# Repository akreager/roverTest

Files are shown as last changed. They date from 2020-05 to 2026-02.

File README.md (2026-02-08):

# Rover Test Platform
Engineering test platform for developing RC rover control and telemetry. Pairs with the [RC Transmitter](https://github.com/akreager/rc-transmitter).

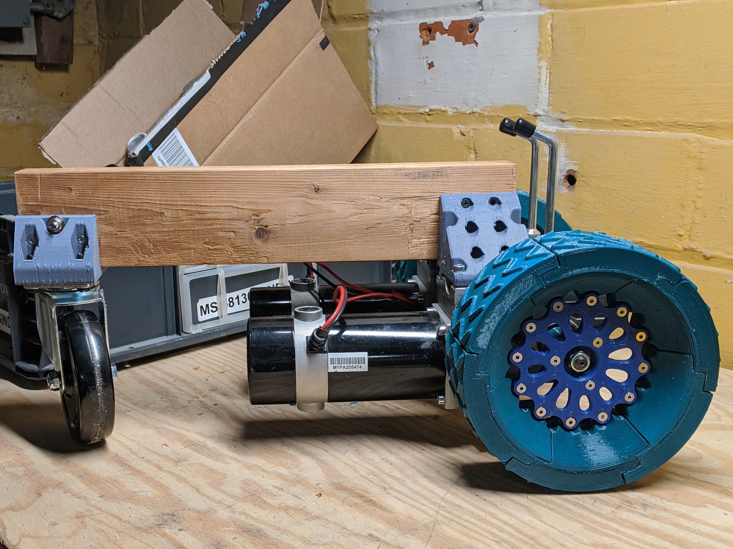
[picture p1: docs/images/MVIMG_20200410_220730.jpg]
Front


## Overview
A small-scale test rover used to develop and validate control, telemetry, and safety features before deploying them on full-size vehicles (e.g. RC snowblower). Receives wireless commands from a custom pistol-grip transmitter and sends back real-time sensor data via nRF24L01+ acknowledge payloads.

### Features
- **Wireless control** via nRF24L01+ with bidirectional telemetry
- **Mixed-mode drive** — throttle and steering via RoboClaw motor controller
- **Telemetry reporting** — battery voltage, board temperatures, motor currents sent back to transmitter each cycle
- **Connection failsafe** — motors stop automatically if radio link is lost for >1 second
- **Motor stop** (M-Stop) — responds to transmitter's M-Stop flag, controls motor enable/disable via digital pin

### Planned
- Joystick-aimed chute control (additional servo/actuator channels)
- Per-vehicle configuration via SD card profiles on transmitter side

## Hardware
- Arduino Mega
- nRF24L01+ radio module (SPI, CE=D49, CSN=D53)
- [Basicmicro RoboClaw](https://www.basicmicro.com/) motor controller (Serial1, address 0x80, 38400 baud)
- Motor enable/disable on D7

## Project Structure
```
RoverTest/
├── main/                 # Receiver firmware (Arduino IDE)
│   └── main.ino          # Radio receive, RoboClaw control, telemetry, failsafe
├── test_sketches/        # Standalone test/reference sketches
│   ├── simpleJoystick/   # Raw joystick → serial output
│   ├── roverJoystick/    # Direct joystick → RoboClaw
│   ├── roverJoyRead/     # Joystick + RoboClaw telemetry → LCD
│   ├── roverRX/          # nRF24 receiver + RoboClaw (precursor to main)
│   ├── roverReceiver/    # Joystick → RoboClaw variant
│   ├── roverRead/        # RoboClaw telemetry → serial LCD
│   ├── roverReadVersion/ # RoboClaw firmware version check
│   ├── PacketSerialMixedPWM/ # RoboClaw mixed mode basic test
│   ├── LCD_Test/         # Serial LCD test
│   └── while/            # LCD + LED loop test
├── stl/                  # 3D printed chassis files
├── docs/                 # Documentation and images
├── LICENSE               # GPLv3
└── README.md
```

## Radio Protocol
The rover receives a `dataPackage` and responds with an `ackPackage` via nRF24L01+ acknowledge payloads. These structs must match the transmitter exactly.

```c
// Transmitter → Rover
struct dataPackage {
  byte throttle;        // 0-127, 64 = stop (RoboClaw mixed mode)
  byte steering;        // 0-127, 64 = center
  bool data_motor_stop; // true = motors disabled
};

// Rover → Transmitter (acknowledge payload)
struct ackPackage {
  byte highBatt, lowBatt;     // Battery voltage, tenths of a volt
  byte highTemp1, lowTemp1;   // Board temp 1, tenths of a degree C
  byte highTemp2, lowTemp2;   // Board temp 2, tenths of a degree C
  byte highIM1, lowIM1;       // Motor 1 current, hundredths of an amp
  byte highIM2, lowIM2;       // Motor 2 current, hundredths of an amp
  bool ack_motor_stop;        // Current motor stop state
};
```

## Dependencies
Install via Arduino IDE Library Manager:
- [RF24](https://github.com/tmrh20/RF24/) (TMRh20 fork)
- [RoboClaw Arduino Library](https://github.com/basicmicro/roboclaw_arduino_library)

## Development
This project is developed with assistance from Claude (Anthropic), used for code architecture, refactoring, and documentation.

## License
This project is licensed under the GNU General Public License v3.0 — see [LICENSE](LICENSE) for details.

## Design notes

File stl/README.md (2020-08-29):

## CAD source
Rover 3D design is being built on [OnShape](https://cad.onshape.com/documents/239133669f4d5c1c58381066/v/e138f06f4808e5e6169b5c82/e/71e3041a4af3a245cfc2c266)

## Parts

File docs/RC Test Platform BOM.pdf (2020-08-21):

RC Test Platform BOM | BOM - RC Test Platform (Main) - Final Assembly

8/21/2020 10:02:41

Document: [1] | RC Test Platform | Open in Onshape
Workspace: [2] | Main [3]
BOM of Assembly: [4] | Final Assembly | BOM Type: | Workspace
Description | | Created: | 2020-08-21 [5]
Part number:
Revision:
State: | RELEASED
ITEM | QTY | NAME | DESCRIPTION [6] | PART NUMBER [7]REVISION | STATE
1 | 1 | Cover | Arduino Mega/Roboclaw Control Box Cover | IN_PROGRESS
2 | 1 | Base | Arduino Mega/Roboclaw Control Box Base Plate | IN_PROGRESS
3 | 4 | Chamfered plain washer normal M8 | Chamfered plain washer normal M8 Steel Zinc Plated | | IN_PROGRESS
4 | 4 | Chamfered plain washer normal M3 | Chamfered plain washer normal M3 Steel Zinc Plated | | IN_PROGRESS
5 | 1 | Caster Bracket | IN_PROGRESS
6 | 4 | Standoff | M3 x 5mm Standoff | IN_PROGRESS
7 | 4 | Socket button head screw M8x1.25 x 30 | Socket button head screw M8x1.25 x 30 Steel Black Oxide | | IN_PROGRESS
8 | 6 | Type A flat washer 1/4 | Type A flat washer 1/4 Steel Zinc Plated | | IN_PROGRESS
9 | 4 | Hex socket head cap screw M6x1.00 x 35 | Hex socket head cap screw M6x1.00 x 35 Stainless Steel | | IN_PROGRESS
10 | 4 | Hex socket head cap screw M6x1.00 x 20 | Hex socket head cap screw M6x1.00 x 20 Stainless Steel | | IN_PROGRESS
11 | 6 | Hex socket head cap screw M3x0.50 x 14 | Hex socket head cap screw M3x0.50 x 14 Steel Black Oxide | | IN_PROGRESS
12 | 4 | Wire Retainer | Dewalt Battery Holder | IN_PROGRESS
13 | 4 | Hex socket head cap screw M3x0.50 x 8 | Hex socket head cap screw M3x0.50 x 8 Steel Black Oxide | | IN_PROGRESS
14 | 1 | Riser Bracket | IN_PROGRESS
15 | 2 | Dewalt DCB | IN_PROGRESS
16 | 4 | 14-16 AWG Male Disconnect | | | IN_PROGRESS
17 | 1 | MC30A_V5 | Roboclaw Motor controller | IN_PROGRESS
18 | 34 8-32 Long Heat-Set Threaded Insert | 93365A142 | IN_PROGRESS
19 | 60 Socket countersunk head cap screw #8-32 x 0.625 Socket countersunk head cap screw #8-32 x 0.625 Stainless Steel | IN_PROGRESS
20 | 4 | Hex thin nut grade A & B M8 | Hex thin nut grade A & B M8 Steel Zinc Plated | | IN_PROGRESS
21 | 2 | Top Gearbox Bracket | IN_PROGRESS
22 | 6 | Hex nut 1/4-20 | Hex nut 1/4-20 Steel Zinc Plated | IN_PROGRESS
23 | 1 | Hex nut 3/8-16 | Hex nut 3/8-16 Steel Zinc Plated | IN_PROGRESS
24 | 2 | M3 Flanged Press-Fit Threaded Insert | | 94510A240 | IN_PROGRESS
25 | 15 M3 Heat-Set Threaded Insert | IN_PROGRESS
26 | 1 | 2x4x18-SS | 18" Long 2x4 | IN_PROGRESS
27 | 4 | Output Shaft | IN_PROGRESS
28 | 4 | Spokes | IN_PROGRESS
29 | 2 | Hub | IN_PROGRESS
30 | 7 | Tube, LH Tread | IN_PROGRESS
31 | 7 | Tube, RH Tread | IN_PROGRESS
32 | 1 | Arduino Mega 2560 | IN_PROGRESS
33 | 2 | Right Cover Plare | IN_PROGRESS
34 | 4 | Gearbox | IN_PROGRESS
35 | 4 | Motor Shaft Cover | IN_PROGRESS
36 | 2 | Left Motor | IN_PROGRESS
37 | 2 | Right Motor | IN_PROGRESS
38 | 2 | Left Cover Plate | IN_PROGRESS
39 | 1 | Antenna base | IN_PROGRESS
40 | 1 | NRF24L01L | IN_PROGRESS
41 | 1 | Antenna top | IN_PROGRESS
42 | 1 | Threaded Rod | IN_PROGRESS
43 | 1 | Threaded Rod | IN_PROGRESS
44 | 1 | Swivel | IN_PROGRESS
45 | 1 | Base | IN_PROGRESS
46 | 1 | Wheel | IN_PROGRESS
47 | 2 | Strain Relief | IN_PROGRESS
48 | 2 | Body | IN_PROGRESS
49 | 1 | LH Lower Gearbox Bracket | | | IN_PROGRESS
50 | 1 | RH Lower Gearbox Bracket | | | IN_PROGRESS
51 | 1 | Hex cap screw 3/8-16 x 2.375 x 1 | Hex cap screw 3/8-16 x 2.375 x 1 Steel | | IN_PROGRESS
52 | 1 | 40x40x10 PC Fan | IN_PROGRESS

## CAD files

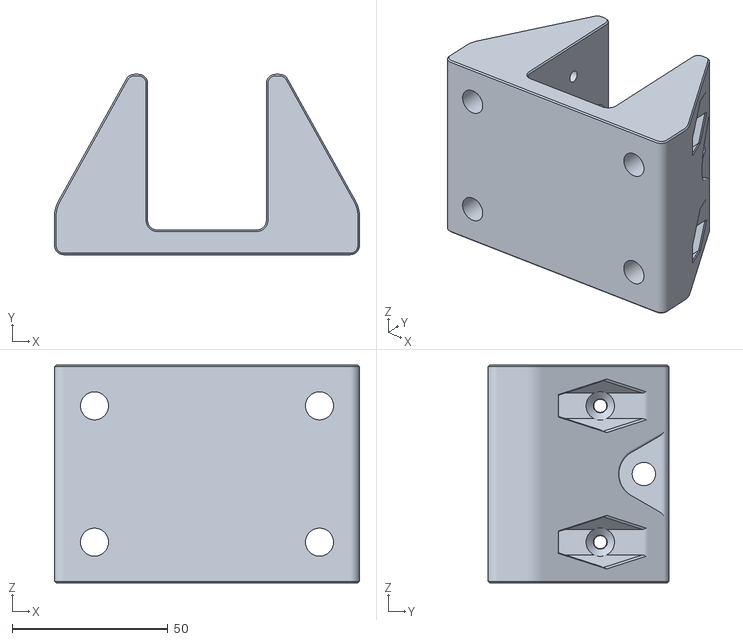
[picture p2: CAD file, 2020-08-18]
stl/Caster Bracket.stl
98.0 x 58.0 x 70.0

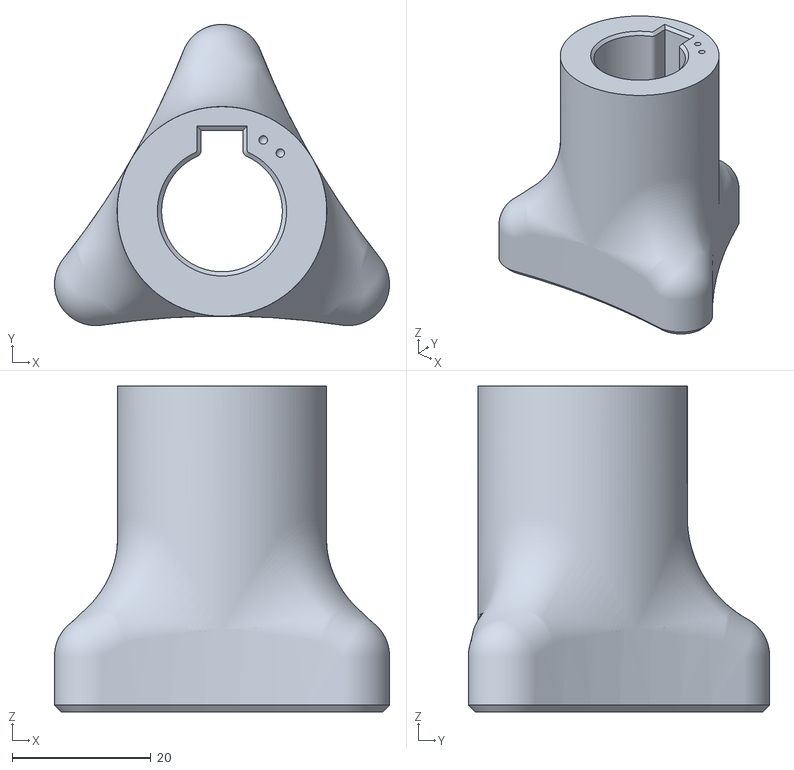
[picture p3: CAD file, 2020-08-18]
stl/Modular Wheel Hub.stl
48.3 x 43.4 x 47.0

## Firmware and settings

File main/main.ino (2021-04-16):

/*
  Optimized fork of nRF24L01 for Arduino & Raspberry Pi/Linux Devices:
  TMRh20/RF24, https://github.com/tmrh20/RF24/
  nRF24/RF24 is licensed under the
  GNU General Public License v2.0

  nRF24 examples used:
  https://howtomechatronics.com/tutorials/arduino/arduino-wireless-communication-nrf24l01-tutorial/
  https://howtomechatronics.com/projects/diy-arduino-rc-transmitter/

  Basicmicro Roboclaw Arduino library and examples:
  https://github.com/basicmicro/roboclaw_arduino_library
*/
//Include libraries
#include <Arduino.h>
#include <SPI.h>
#include <nRF24L01.h>
#include <RF24.h>
#include <RoboClaw.h>

//Declare C++ functions to be used
void failsafe_connection_dropped();
void read_rf_data();
void read_roboclaw_data();
void update_acknowledge_package();
void disable_motors();
void enable_motors();

//nRF24 connected to hardware SPI at address 00001
#define CE_PIN 49
#define CSN_PIN 53
RF24 radio(CE_PIN, CSN_PIN);
const byte nRFaddress[6] = "00001";

//Roboclaw connected to Serial1 at address 0x80
RoboClaw roboclaw(&Serial1, 10000);
#define roboclaw_address 0x80
#define motor_stop_pin 7

//Declare variables
uint16_t rawBattery = 0;
uint16_t rawTemp1 = 0;
uint16_t rawTemp2 = 0;
int16_t rawCurrentMotor1 = 0;
int16_t rawCurrentMotor2 = 0;
unsigned long lastReceiveTime = 0;
unsigned long currentTime = 0;
int readInterval = 0;
int readThreshold = 10;

//Declare flags
bool flag_motor_stop = true;

//package to contain incoming data
struct dataPackage {
  byte throttle;
  byte steering;
  bool data_motor_stop;
};
dataPackage data;

//package to contain outgoing acknowledge data
struct ackPackage {
  byte highBatt;
  byte lowBatt;
  byte highTemp1;
  byte lowTemp1;
  byte highTemp2;
  byte lowTemp2;
  byte highIM1;
  byte lowIM1;
  byte highIM2;
  byte lowIM2;
  bool ack_motor_stop;
};
ackPackage ack;

void setup() {
  pinMode(motor_stop_pin, OUTPUT);

  //start wireless connection
  update_acknowledge_package();
  radio.begin();
  radio.openReadingPipe(0, nRFaddress);
  radio.setDataRate(RF24_250KBPS);
  radio.setPALevel(RF24_PA_MIN);
  radio.enableAckPayload();
  radio.writeAckPayload(0, &ack, sizeof(ackPackage));
  radio.startListening();
  
  //Communciate with roboclaw at 38400 baud
  failsafe_connection_dropped();
  roboclaw.begin(38400);
  roboclaw.ForwardBackwardMixed(roboclaw_address, data.throttle);
  roboclaw.LeftRightMixed(roboclaw_address, data.steering);
}

void loop() {
  // Check whether there is data to be received
  if (radio.available()) {
    read_rf_data();
  }

  //verify connection is alive
  currentTime = millis();
  if (currentTime - lastReceiveTime > 1000 ) {
    //failsafe condition if connection lost
    failsafe_connection_dropped();
  }

  //retreive data from roboclaw for acknowledge payload
  if (readInterval >= readThreshold) {
    read_roboclaw_data();
    readInterval = 0;
  }
  readInterval++;
}

void failsafe_connection_dropped() {
  //Failsafe condition if there is no radio connection
  disable_motors();
  data.throttle = 64;
  data.steering = 64;
}

void read_rf_data() {
  //Read data from nRF module
  radio.read(&data, sizeof(dataPackage));
    lastReceiveTime = millis();
    radio.writeAckPayload(0, &ack, sizeof(ackPackage));

    //Forward received data roboclaw
    roboclaw.ForwardBackwardMixed(roboclaw_address, data.throttle);
    roboclaw.LeftRightMixed(roboclaw_address, data.steering);

    //Check M-Stop flag
    if (flag_motor_stop == true && data.data_motor_stop == false) {
      enable_motors();
    }
    else if (flag_motor_stop == false && data.data_motor_stop == true) {
      disable_motors();
    }
}

void read_roboclaw_data() {
  //Read data fromm roboclaw
  //main battery voltage, tenths of a volt
  bool valid1;
  rawBattery = roboclaw.ReadMainBatteryVoltage(roboclaw_address, &valid1);
  //rawBattery = roboclaw.ReadMainBatteryVoltage(roboclaw_address);

  //roboclaw board temperature 1, tenths of a degree
  if (roboclaw.ReadTemp(roboclaw_address, rawTemp1)) {};

  //roboclaw board temperature 2, tenths of a degree
  if (roboclaw.ReadTemp2(roboclaw_address, rawTemp2)) {};

  //instantaneous mmotor amp draw, hundredths of an amp
  if (roboclaw.ReadCurrents(roboclaw_address, rawCurrentMotor1, rawCurrentMotor2)) {};

  //update acknowledge packet with new data from roboclaw
  update_acknowledge_package();
}

void update_acknowledge_package() {
  ack.highBatt = highByte(rawBattery);
  ack.lowBatt = lowByte(rawBattery);
  ack.highTemp1 = highByte(rawTemp1);
  ack.lowTemp1 = lowByte(rawTemp1);
  ack.highTemp2 = highByte(rawTemp2);
  ack.lowTemp2 = lowByte(rawTemp2);
  ack.highIM1 = highByte(rawCurrentMotor1);
  ack.lowIM1 = lowByte(rawCurrentMotor1);
  ack.highIM2 = highByte(rawCurrentMotor2);
  ack.lowIM2 = lowByte(rawCurrentMotor2);
  ack.ack_motor_stop = flag_motor_stop;
}

void disable_motors() {
  digitalWrite(motor_stop_pin, LOW);
  flag_motor_stop = true;
}

void enable_motors() {
  digitalWrite(motor_stop_pin, HIGH);
  flag_motor_stop = false;
}

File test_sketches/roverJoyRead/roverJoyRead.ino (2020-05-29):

//Basicmicro Arduino library and examples:
//https://github.com/basicmicro/roboclaw_arduino_library

#include "RoboClaw.h"

RoboClaw roboclaw(&Serial1, 10000);

#define address 0x80

//Serial LCD commands
#define COMMAND 0xFE
#define CLEAR   0x01
#define LINE0   0x80
#define LINE1   0xC0

unsigned int rawBattery = 0;
unsigned int rawTemp1 = 0;
unsigned int rawTemp2 = 0;
int rawCurrentMotor1 = 0;
int rawCurrentMotor2 = 0;
int vrX = A0;
int vrY = A1;
int valX = 64;
int valY = 64;
int readInterval = 0;
int readThreshold = 10;

void setup() {
  // put your setup code here, to run once:
  //debug serial
  Serial.begin(9600);

  //Communciate with roboclaw at 38400 baud
  roboclaw.begin(38400);
  delay(100);
  roboclaw.ForwardBackwardMixed(address, valY);
  roboclaw.LeftRightMixed(address, valX);
  delay(100);

  //Communicate with serial LCD at 9600 baud
  Serial2.begin(9600);
  clearLCD();
  delay(100);

}

void loop() {
  // put your main code here, to run repeatedly:
  readInterval++;

  valX = map(analogRead(vrX), 0, 1023, 0, 127);
  valY = map(analogRead(vrY), 0, 1023, 127, 0);

  roboclaw.ForwardBackwardMixed(address, valY);
  roboclaw.LeftRightMixed(address, valX);

  if (readInterval >= readThreshold) {
    updateLCD1();
    readInterval = 0;
  }
}

void clearLCD(void)
{
  Serial2.write(COMMAND);
  Serial2.write(CLEAR);
}

void updateLCD0(void)
{
  bool valid1;

  //Read data fromm roboclaw
  rawBattery = roboclaw.ReadMainBatteryVoltage(address, &valid1);
  if (roboclaw.ReadTemp(address, rawTemp1)) {};
  if (roboclaw.ReadTemp2(address, rawTemp2)) {};
  int mainBattery = rawBattery / 10;
  int temp1 = rawTemp1 / 10;
  int temp2 = rawTemp2 / 10;

  //Display main voltage
  if (valid1) {
    Serial2.write(COMMAND);
    Serial2.write(LINE0);
    Serial2.print(mainBattery);
    Serial2.print(F("."));
    Serial2.print(rawBattery - (mainBattery * 10));
    Serial2.print(F(" V   "));
  }
  else {
    Serial2.write(COMMAND);
    Serial2.write(LINE0);
    Serial2.print(F("INV  "));
  }

  //Display board temperature 1
  Serial2.write(COMMAND);
  Serial2.write(LINE0 + 8);
  Serial2.print(temp1);
  Serial2.print(F("."));
  Serial2.print(rawTemp1 - (temp1 * 10));
  Serial2.print((char)223);
  Serial2.print("C   ");

  //Display board temperature 2
  Serial2.write(COMMAND);
  Serial2.write(LINE1 + 8);
  Serial2.print(temp2);
  Serial2.print(F("."));
  Serial2.print(rawTemp2 - (temp2 * 10));
  Serial2.print((char)223);
  Serial2.print("C  ");
}

void updateLCD1(void)
{
  bool valid1;

  //Read data fromm roboclaw
  rawBattery = roboclaw.ReadMainBatteryVoltage(address, &valid1);
  if (roboclaw.ReadTemp(address, rawTemp1)) {};
  if (roboclaw.ReadCurrents(address, rawCurrentMotor1, rawCurrentMotor2)) {};
  int mainBattery = rawBattery / 10;
  int temp1 = rawTemp1 / 10;
  int currentM1 = rawCurrentMotor1 / 100;
  int currentM2 = rawCurrentMotor2 / 100;

  //Display main voltage
  if (valid1) {
    Serial2.write(COMMAND);
    Serial2.write(LINE0);
    Serial2.print(mainBattery);
    Serial2.print(F("."));
    Serial2.print(rawBattery - (mainBattery * 10));
    Serial2.print(F("V   "));
  }
  else {
    Serial2.write(COMMAND);
    Serial2.write(LINE0);
    Serial2.print(F("INV  "));
  }

  //Display board temperature 1
  Serial2.write(COMMAND);
  Serial2.write(LINE0 + 8);
  Serial2.print(temp1);
  Serial2.print(F("."));
  Serial2.print(rawTemp1 - (temp1 * 10));
  Serial2.print((char)223);
  Serial2.print("C   ");

  //Display Motor 1 current
  Serial2.write(COMMAND);
  Serial2.write(LINE1);
  Serial2.print(currentM1);
  Serial2.print(F("."));
  Serial2.print(rawCurrentMotor1 - (currentM1 * 100));
  Serial2.print(F("A  "));

  //Display Motor 2 current
  Serial2.write(COMMAND);
  Serial2.write(LINE1 + 8);
  Serial2.print(currentM2);
  Serial2.print(F("."));
  Serial2.print(rawCurrentMotor2 - (currentM2 * 100));
  Serial2.print(F("A  "));
}

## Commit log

2020-05-27 baud rate corrected. read more data.
    [roverRead.ino, roverReadVersion.ino]
2020-05-29 reset roboclaw to default baud rate
    [roverJoystick.ino]
2020-05-29 Create roverJoyRead.ino
    preliminary rover receiver code. communication between arduino mega and roboclaw mostly complete. ready to add wireless.
2020-08-17 Initial migration from Arduino IDE to PlatformIO/VS Code
2020-08-18 Add current 3D stl files and link to 3D design source
    [Caster Bracket.stl, Modular Wheel Hub.stl]
2020-08-21 Update README.md
    link updated to v3 assembly
2020-08-21 add arduino mega/roboclaw control box
2020-08-21 Add BOM
2020-08-28 Create roboclaw rc.cfg
    [roboclaw rc.cfg]
2020-08-29 Point README to OnShape assembly version 4
2021-04-16 Make Arduino source file
2021-04-16 Arduino file structure
2026-02-08 Revive project: restructure for Arduino IDE, rewrite README
    Port from PlatformIO/VS Code to Arduino IDE project structure.
    - Move src/main/main.ino to main/main.ino
    - Organize test sketches into test_sketches/ subfolders:
    simpleJoystick, roverJoystick, roverJoyRead, roverRX,
    roverReceiver, roverRead, roverReadVersion,
    PacketSerialMixedPWM, LCD_Test, while
    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
